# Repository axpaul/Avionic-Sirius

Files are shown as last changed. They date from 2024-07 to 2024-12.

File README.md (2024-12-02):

# Avionic-Sirius
*Sirius experimental rocket avionic (On-board electronics), Version 2024 launched at C'space*

*CC BY-NC-SA 4.0, Copyright 2023 Miailhe Paul, all rights reserved*

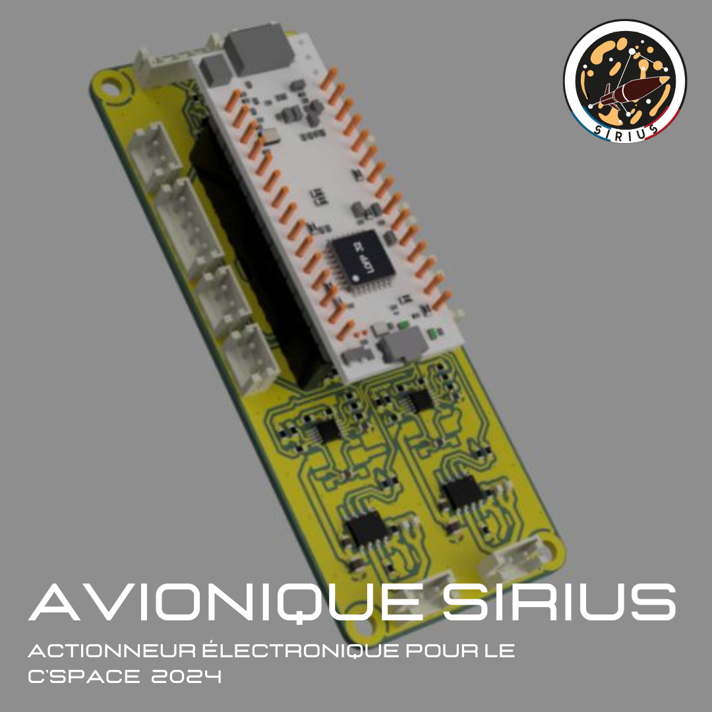
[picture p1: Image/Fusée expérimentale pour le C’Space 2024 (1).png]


# MotorShield Controller

Le **MotorShield Controller** est une carte d'actionneur conçue pour piloter deux moteurs DC. Elle intègre des circuits en pont en H et des capteurs de courant basés sur des résistances shunt, permettant la détection d'événements, la protection contre les surintensités, le contrôle PWM, ainsi que l'indication visuelle de la direction de rotation des moteurs.

---

## Composants principaux

### 1. **Hex Schmitt-Trigger Inverter (74HC14)**
- **Description** : Inverseur logique avec seuils Schmitt pour améliorer l'immunité aux bruits.  
- **Caractéristiques** :
  - Fonctionne avec des signaux LSTTL, CMOS, NMOS, et TTL.
  - Plage de tension de fonctionnement : 2.0V à 6.0V.
  - Immunité élevée au bruit et faible courant d'entrée.

---

### 2. **Optocoupleurs (ACPL-214)**
- **Description** : Optocoupleurs à gain élevé pour une isolation électrique optimale.  
- **Caractéristiques** :
  - Isolation de tension jusqu’à 3000 VRMS.

---

### 3. **Data Converter Isolator (ADuM1281)**
- **Description** : Isolateur numérique double canal pour la transmission de données.  
- **Caractéristiques** :
  - Fonctionne avec une alimentation de 3.3V.
  - Débit de données jusqu'à 100 Mbps.
  - Faible délai de propagation (23 ns).

---

### 4. **INA381A et INA381B – Détection de surintensité**
- **Description** : Amplificateurs de détection de courant avec comparateurs intégrés.  
- **Caractéristiques** :
  - Détection de courants d’entrée entre 10 mA et 3 A.
  - Seuils configurables pour les surintensités (par ex. : 1A).
  - Fonctionnement avec une tension de 3.3V.
  - Intègre une résistance de shunt de 22 mΩ pour la détection.

---

### 5. **DRV8872 – Pilote de moteur DC brossé avec rapport d’erreurs**
- **Description** : Pilote pour moteurs DC avec contrôle PWM.  
- **Caractéristiques** :
  - Plage de tension : 6.5V à 45V.
  - Courant supporté jusqu’à 3.6A.
  - Intègre des protections (UVLO, OCP, TSD) et un rapport d'état des erreurs.
  - Supporte les modes veille et actif avec contrôle de la direction et de la vitesse via PWM.

---

### 6. **Indicateurs LED de direction du moteur**
- **Description** : Circuit simple avec LEDs et résistances pour indiquer la direction de rotation du moteur.  
- **Caractéristiques** :
  - Confirmation visuelle de la rotation du moteur sans connexion supplémentaire.
  - Permet de tester et de vérifier facilement la logique de contrôle.

---

### 7. **Configuration en pont (JP5)**
- **Description** : Jumper configurable pour définir les fonctionnalités d'entrée ou de sortie.  
- **Caractéristiques** :
  - Évite les conflits d’assignation en définissant clairement les modes de fonctionnement.
 
## Licence 



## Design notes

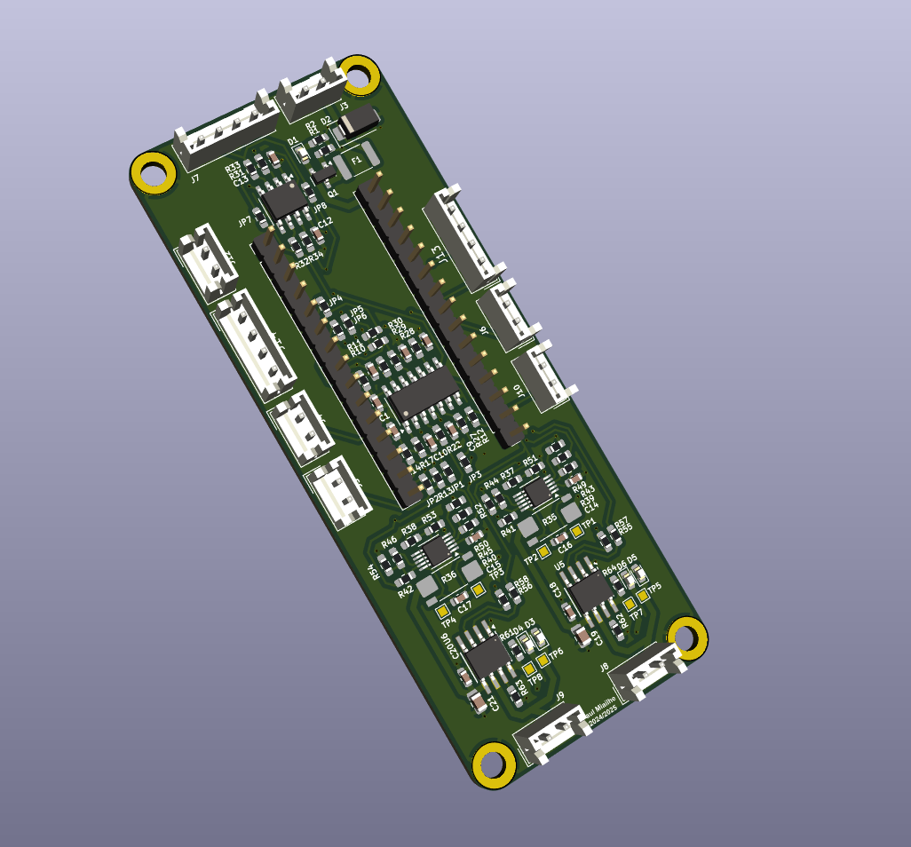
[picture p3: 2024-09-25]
Image/image.png

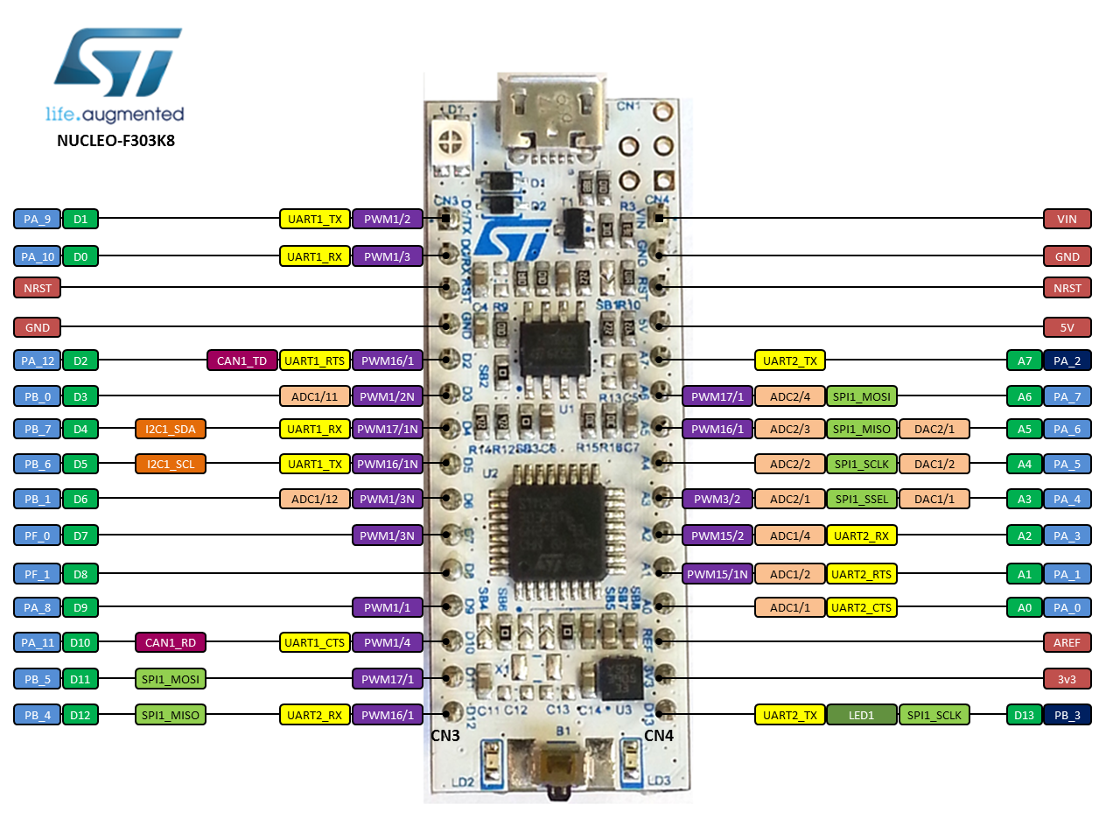
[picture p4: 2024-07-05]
Current-Sensor/nucleo_f303k8_2017_10_10.png

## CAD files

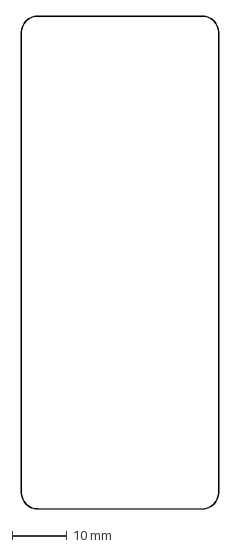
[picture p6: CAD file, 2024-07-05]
PCB-N2.dxf
36.0 x 90.0 mm

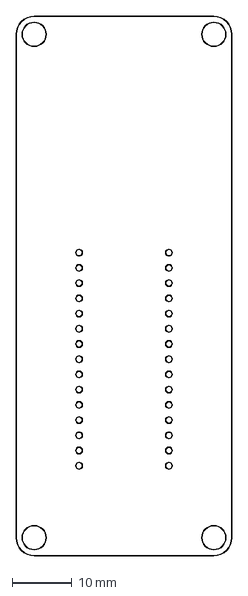
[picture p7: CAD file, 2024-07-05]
PCB-N1.dxf
36.0 x 90.0 mm

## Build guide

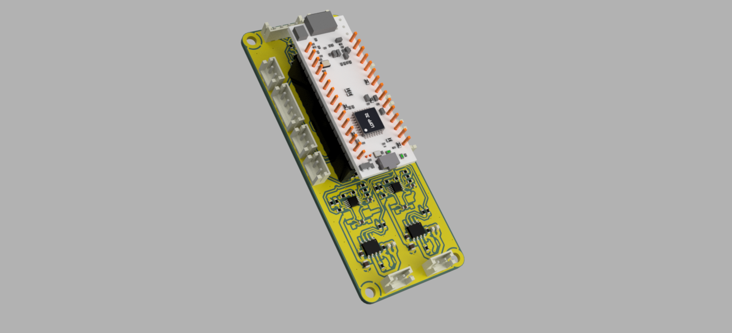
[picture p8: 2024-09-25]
Image/Assemblage_v10.png

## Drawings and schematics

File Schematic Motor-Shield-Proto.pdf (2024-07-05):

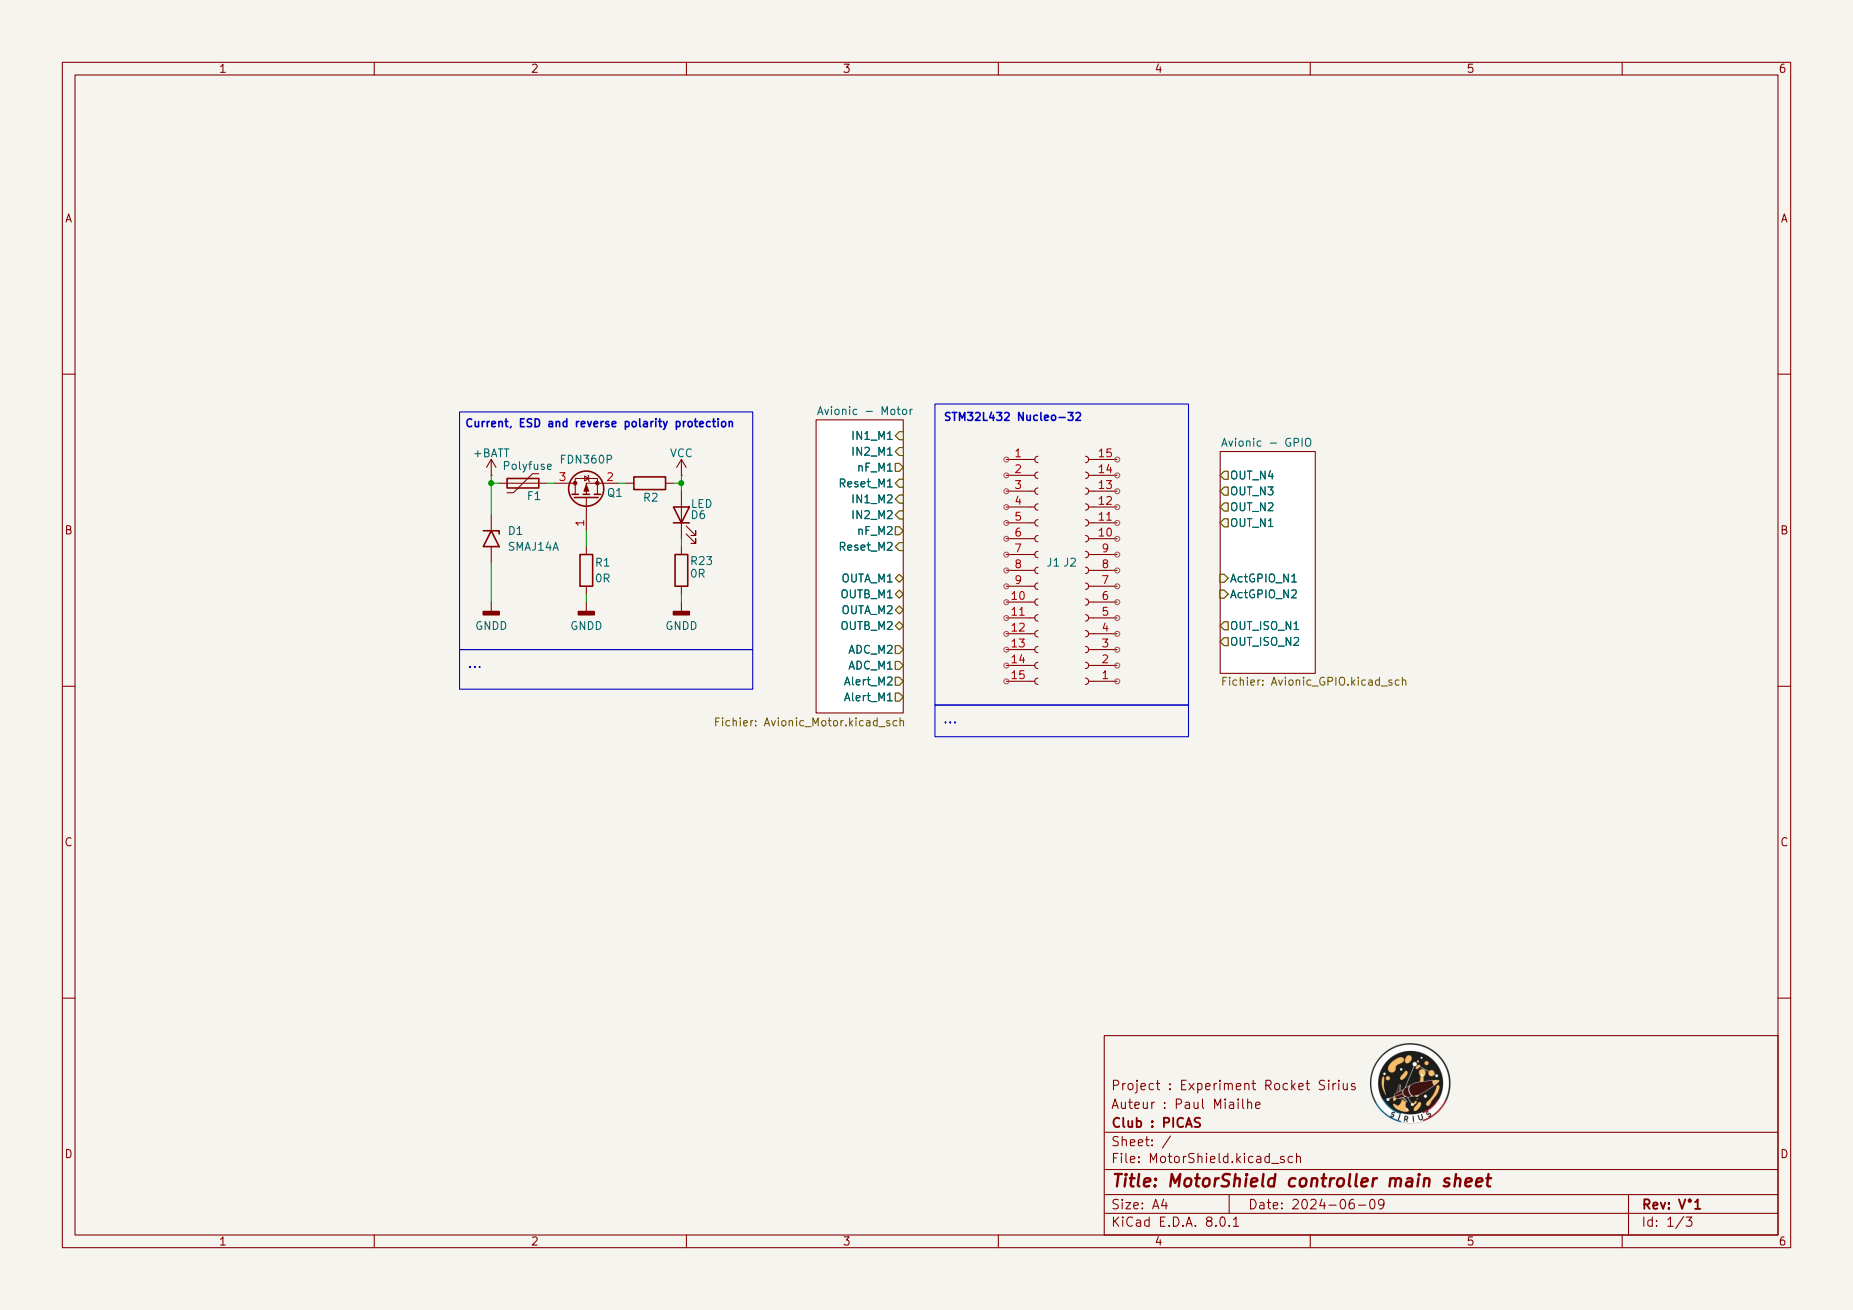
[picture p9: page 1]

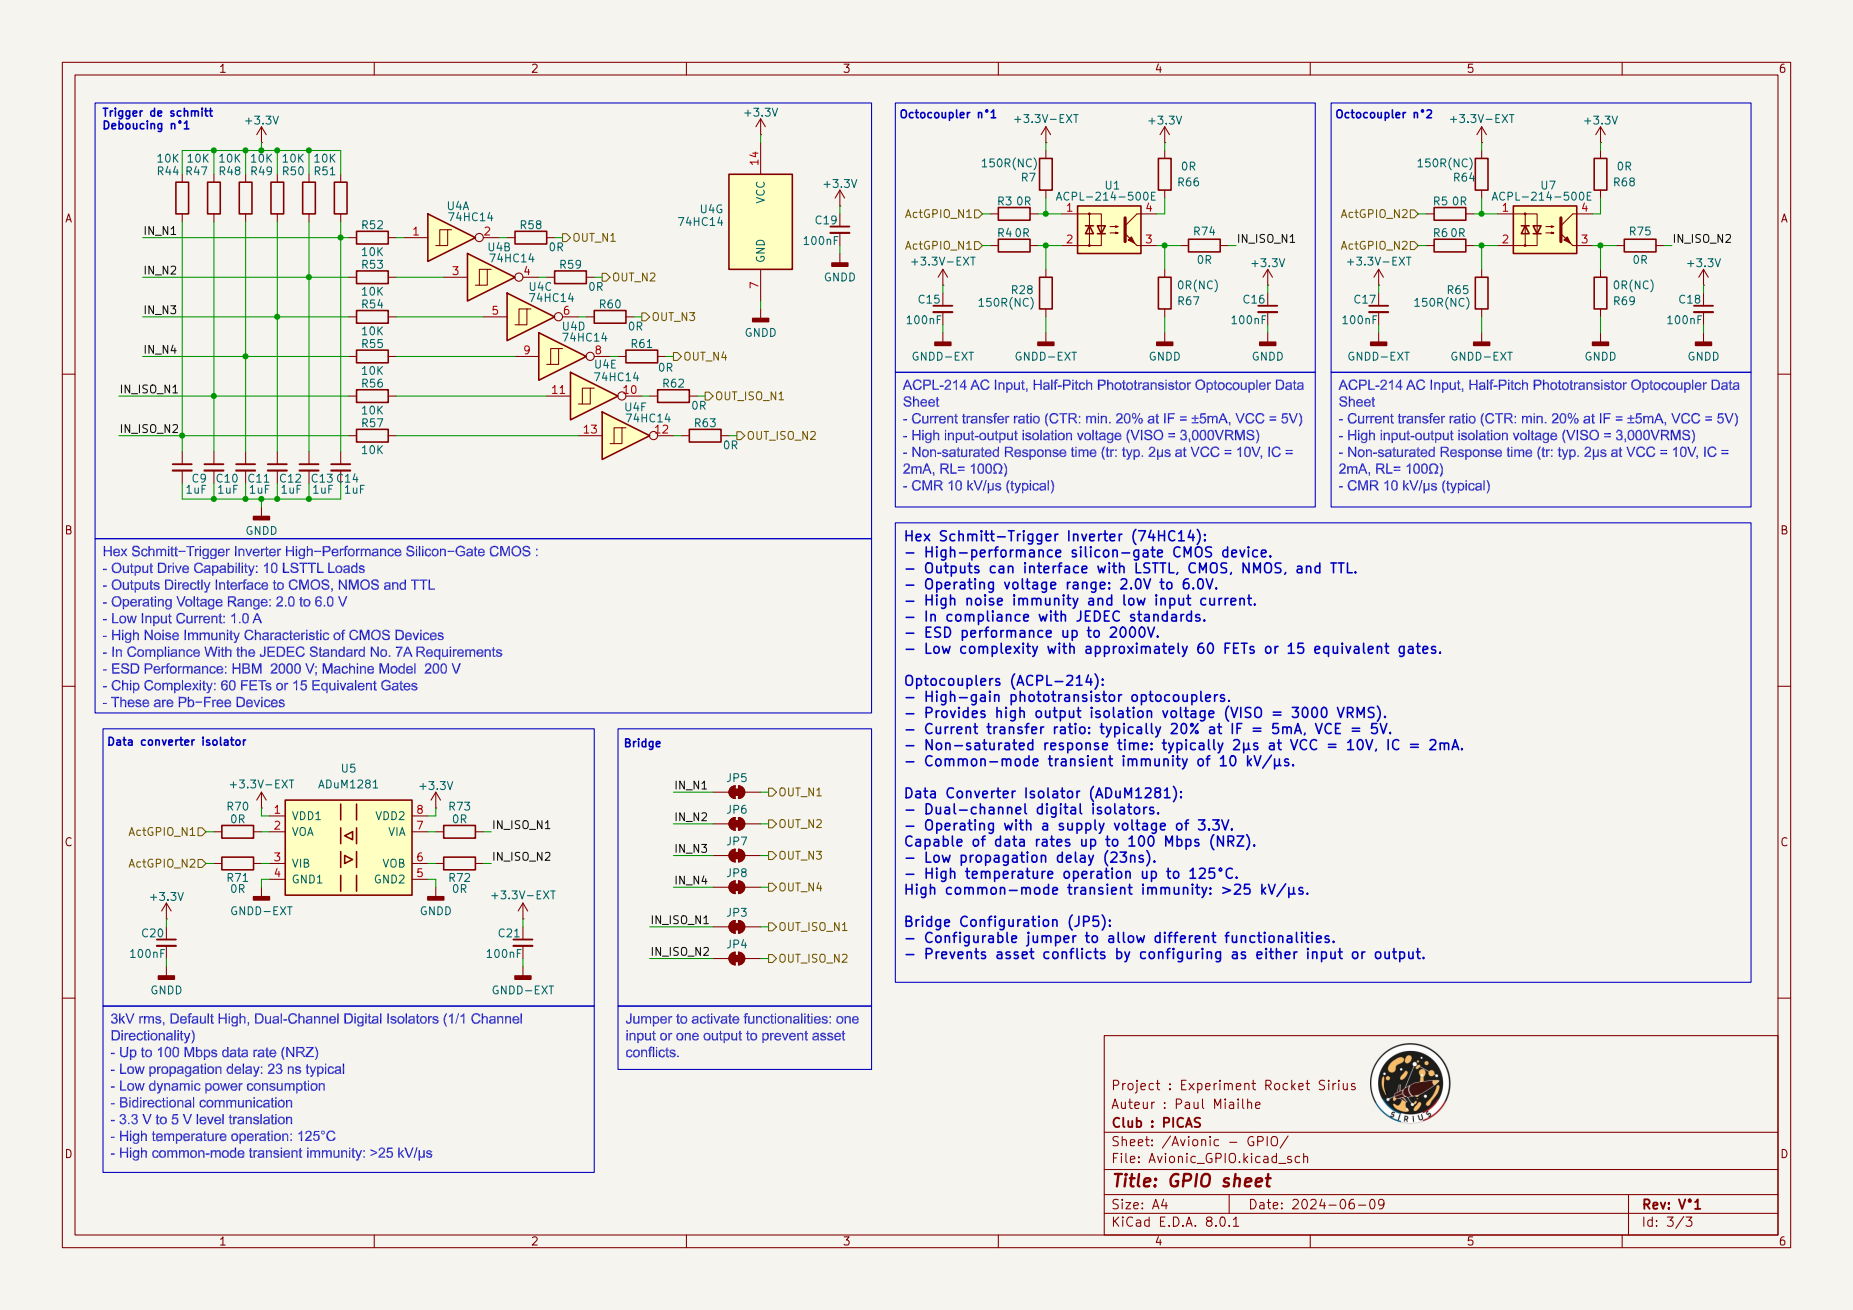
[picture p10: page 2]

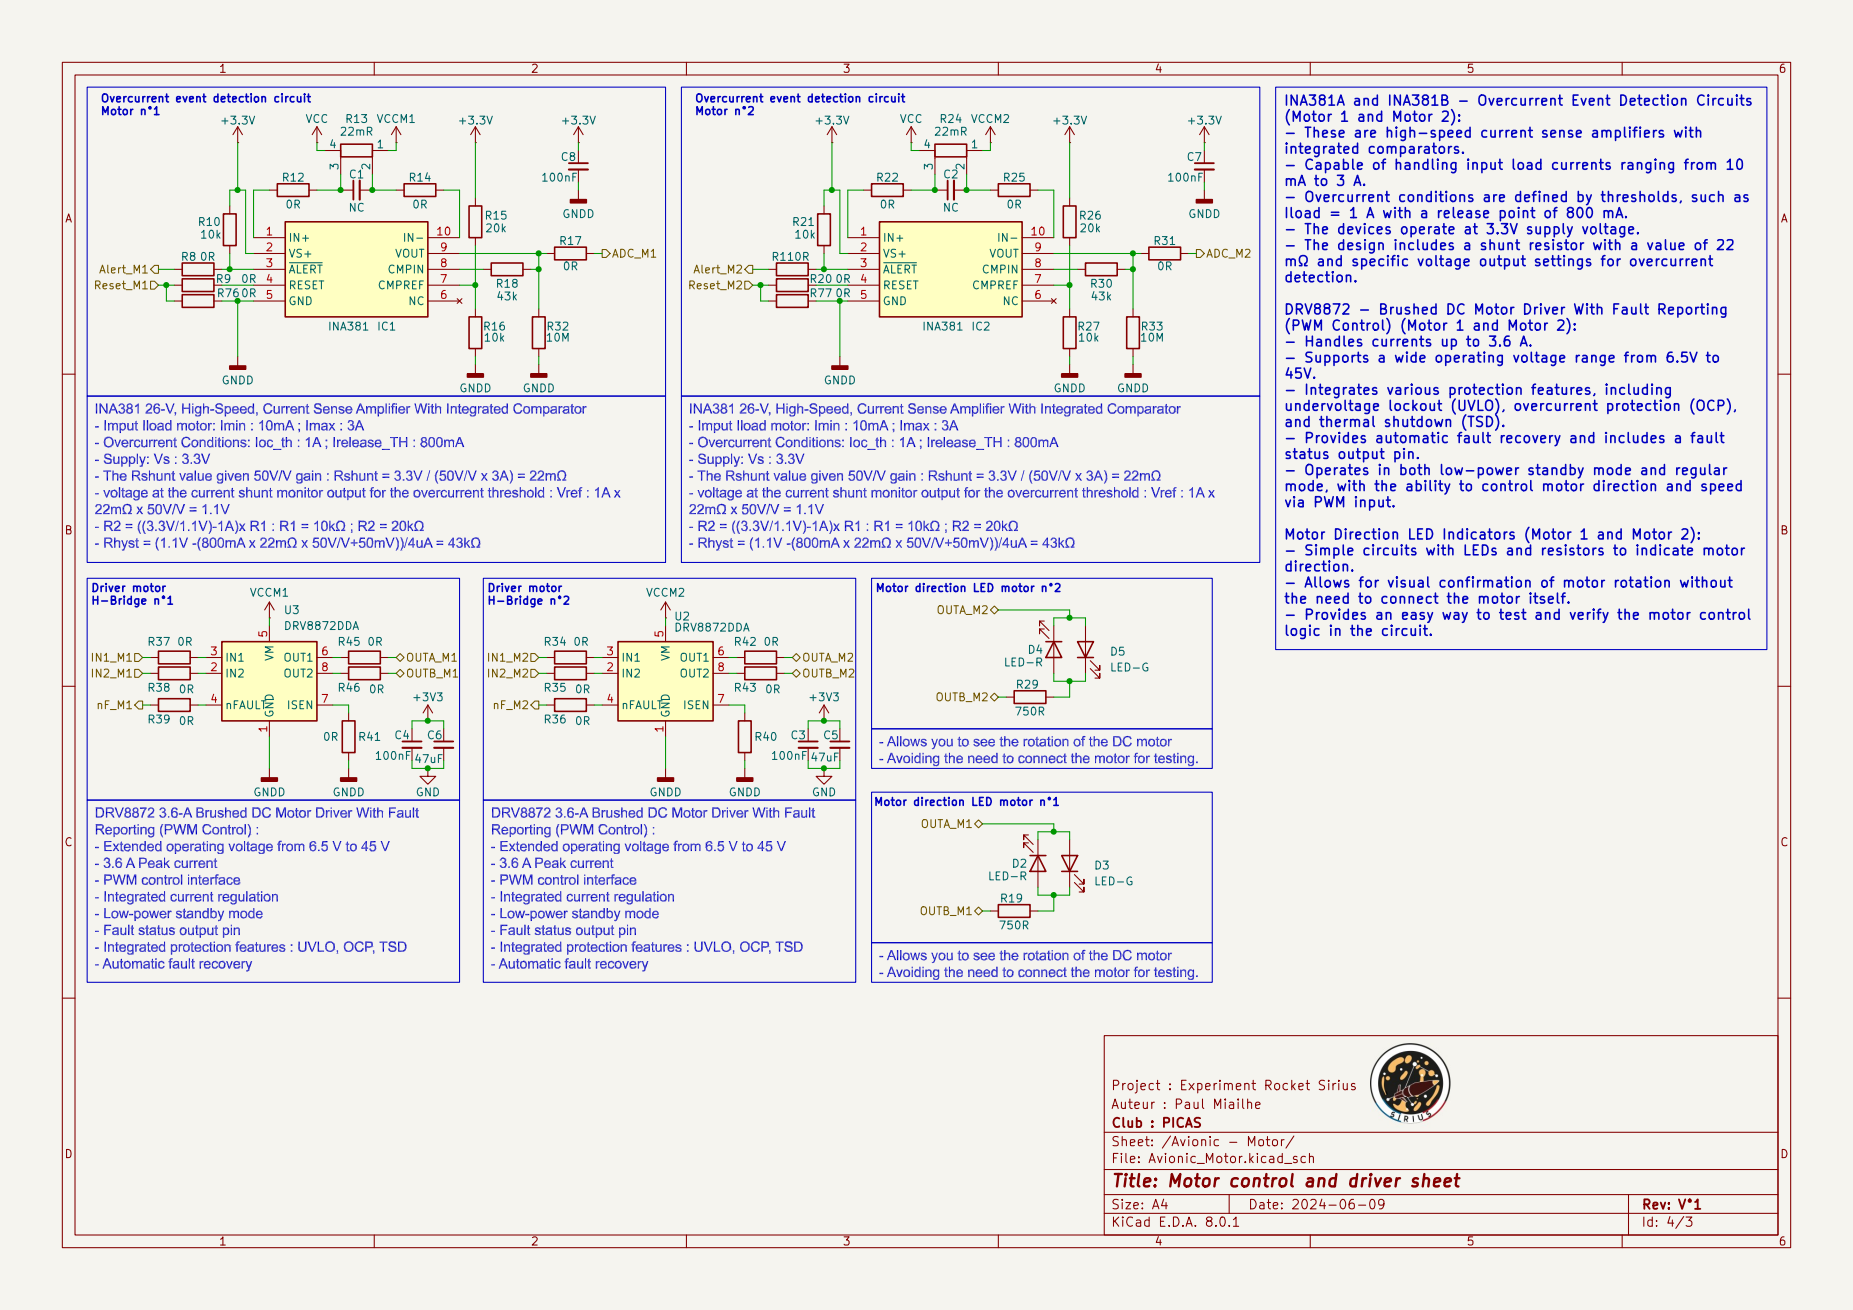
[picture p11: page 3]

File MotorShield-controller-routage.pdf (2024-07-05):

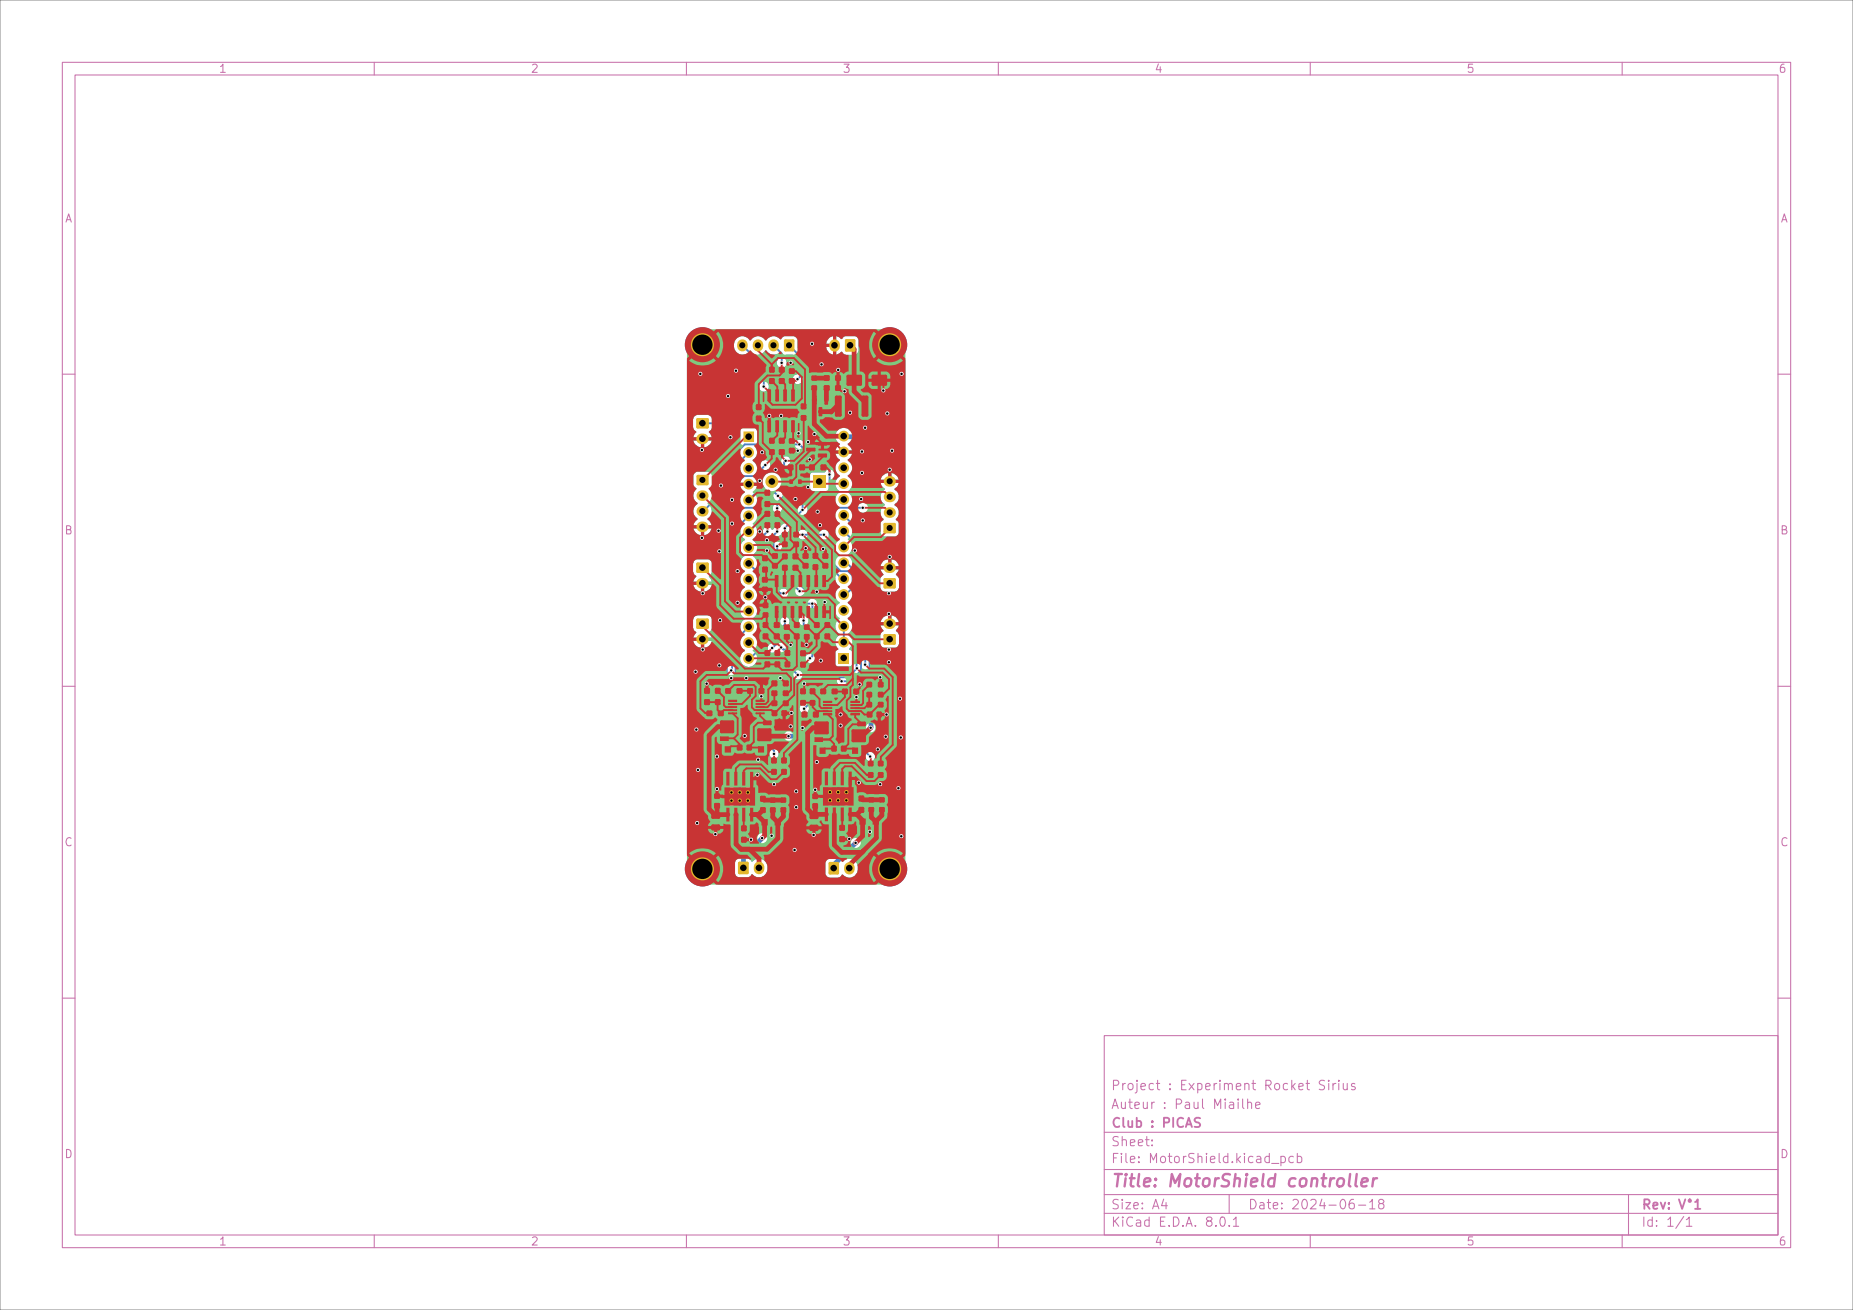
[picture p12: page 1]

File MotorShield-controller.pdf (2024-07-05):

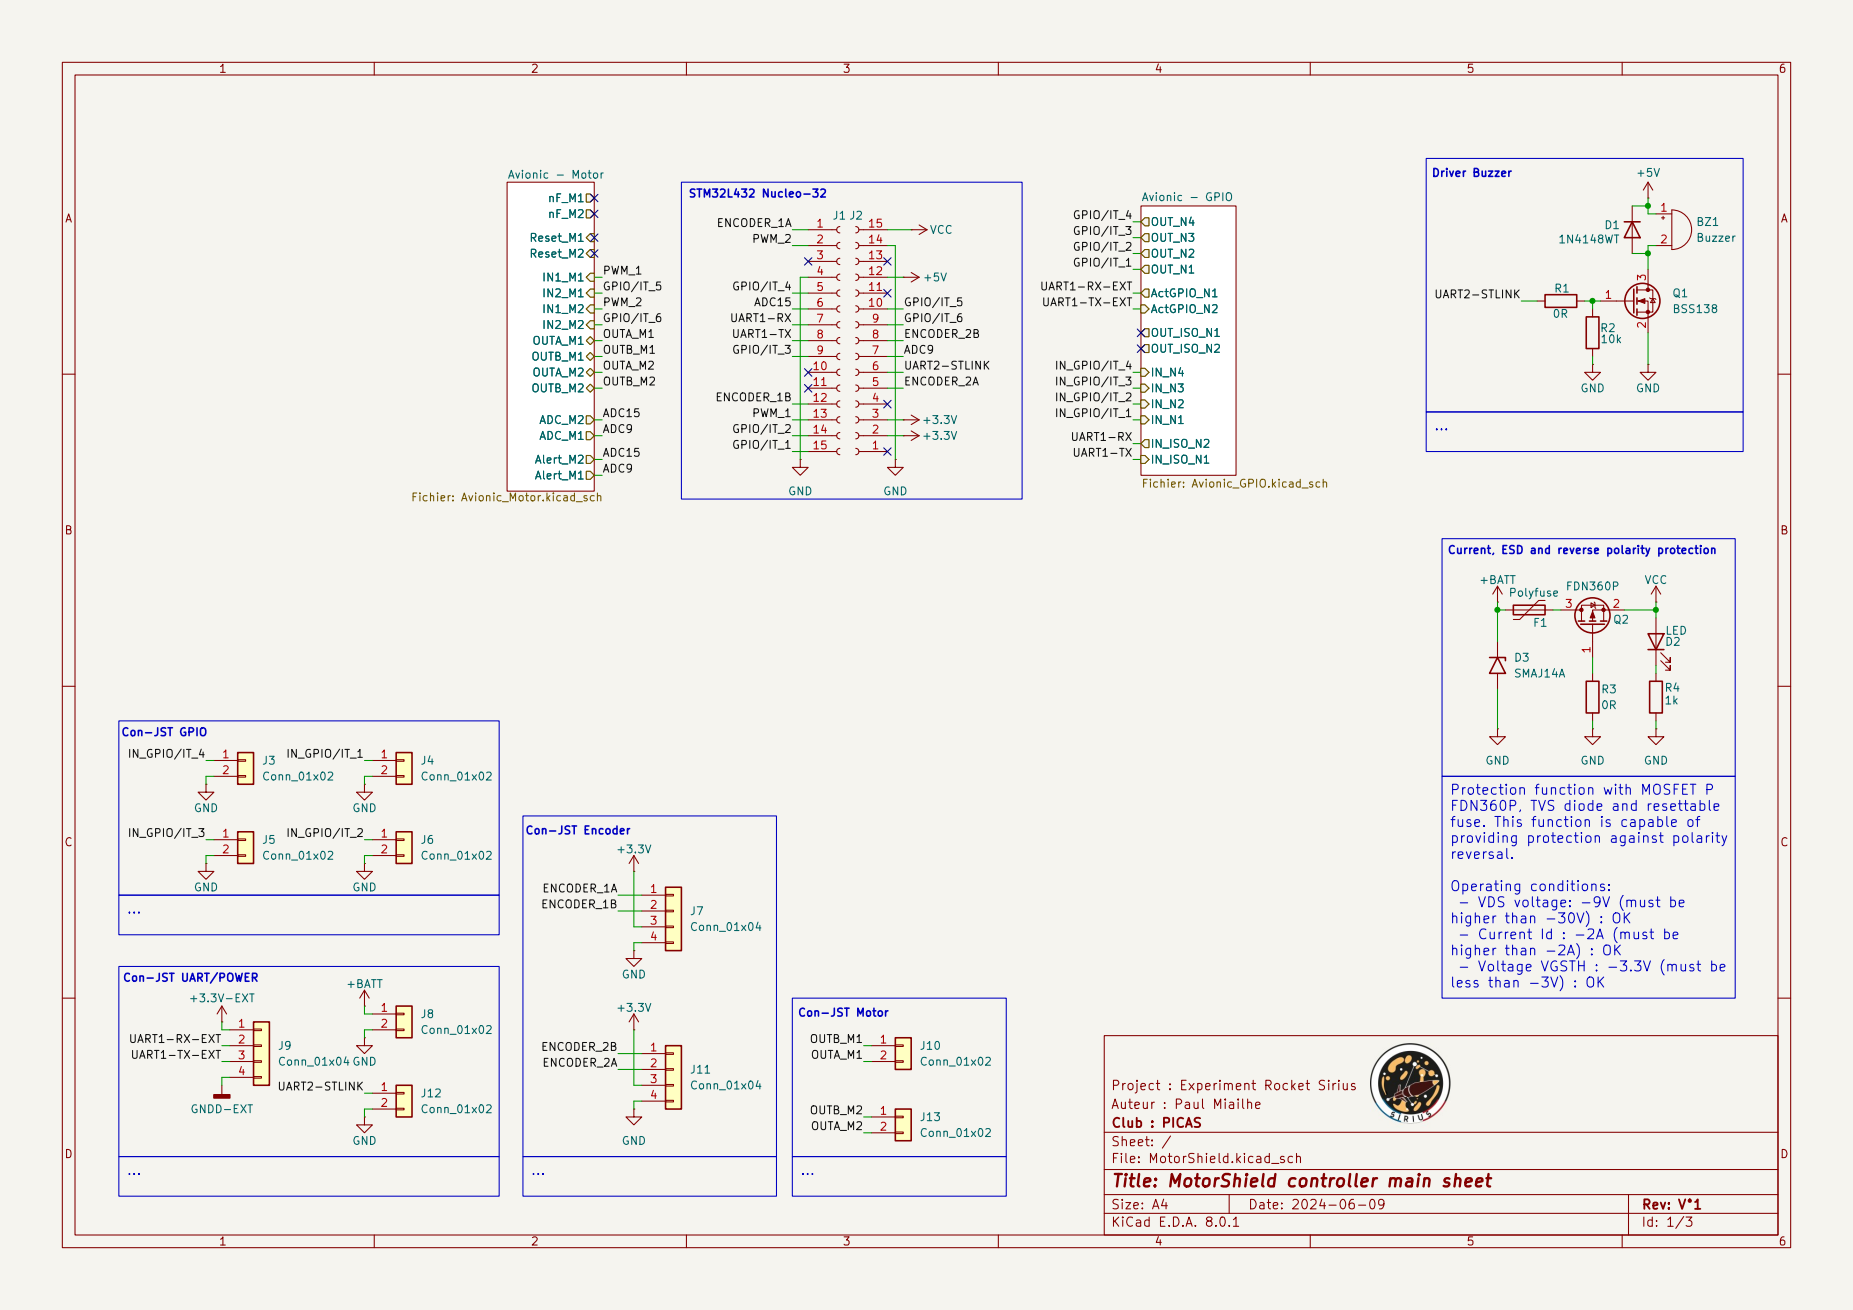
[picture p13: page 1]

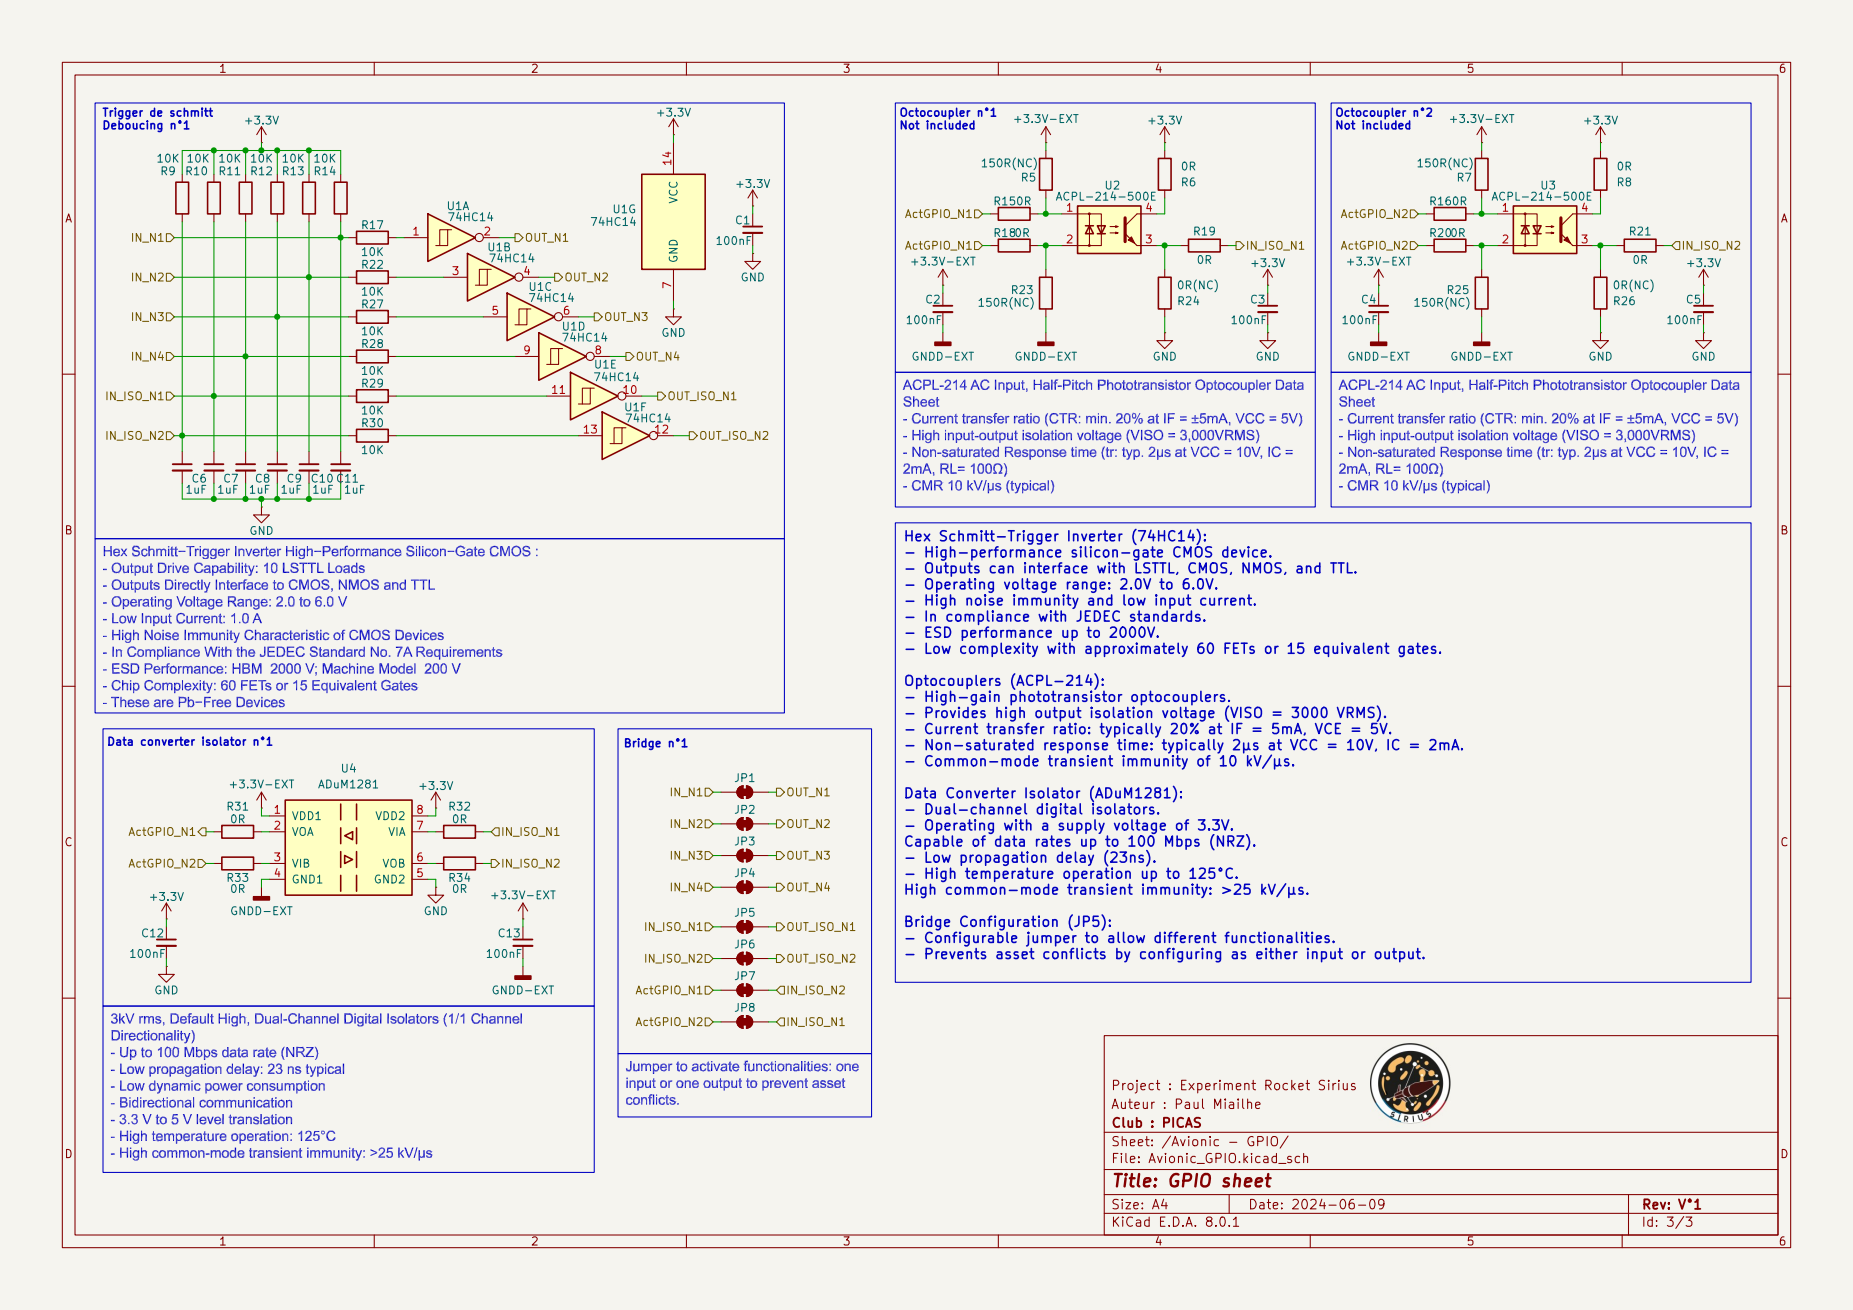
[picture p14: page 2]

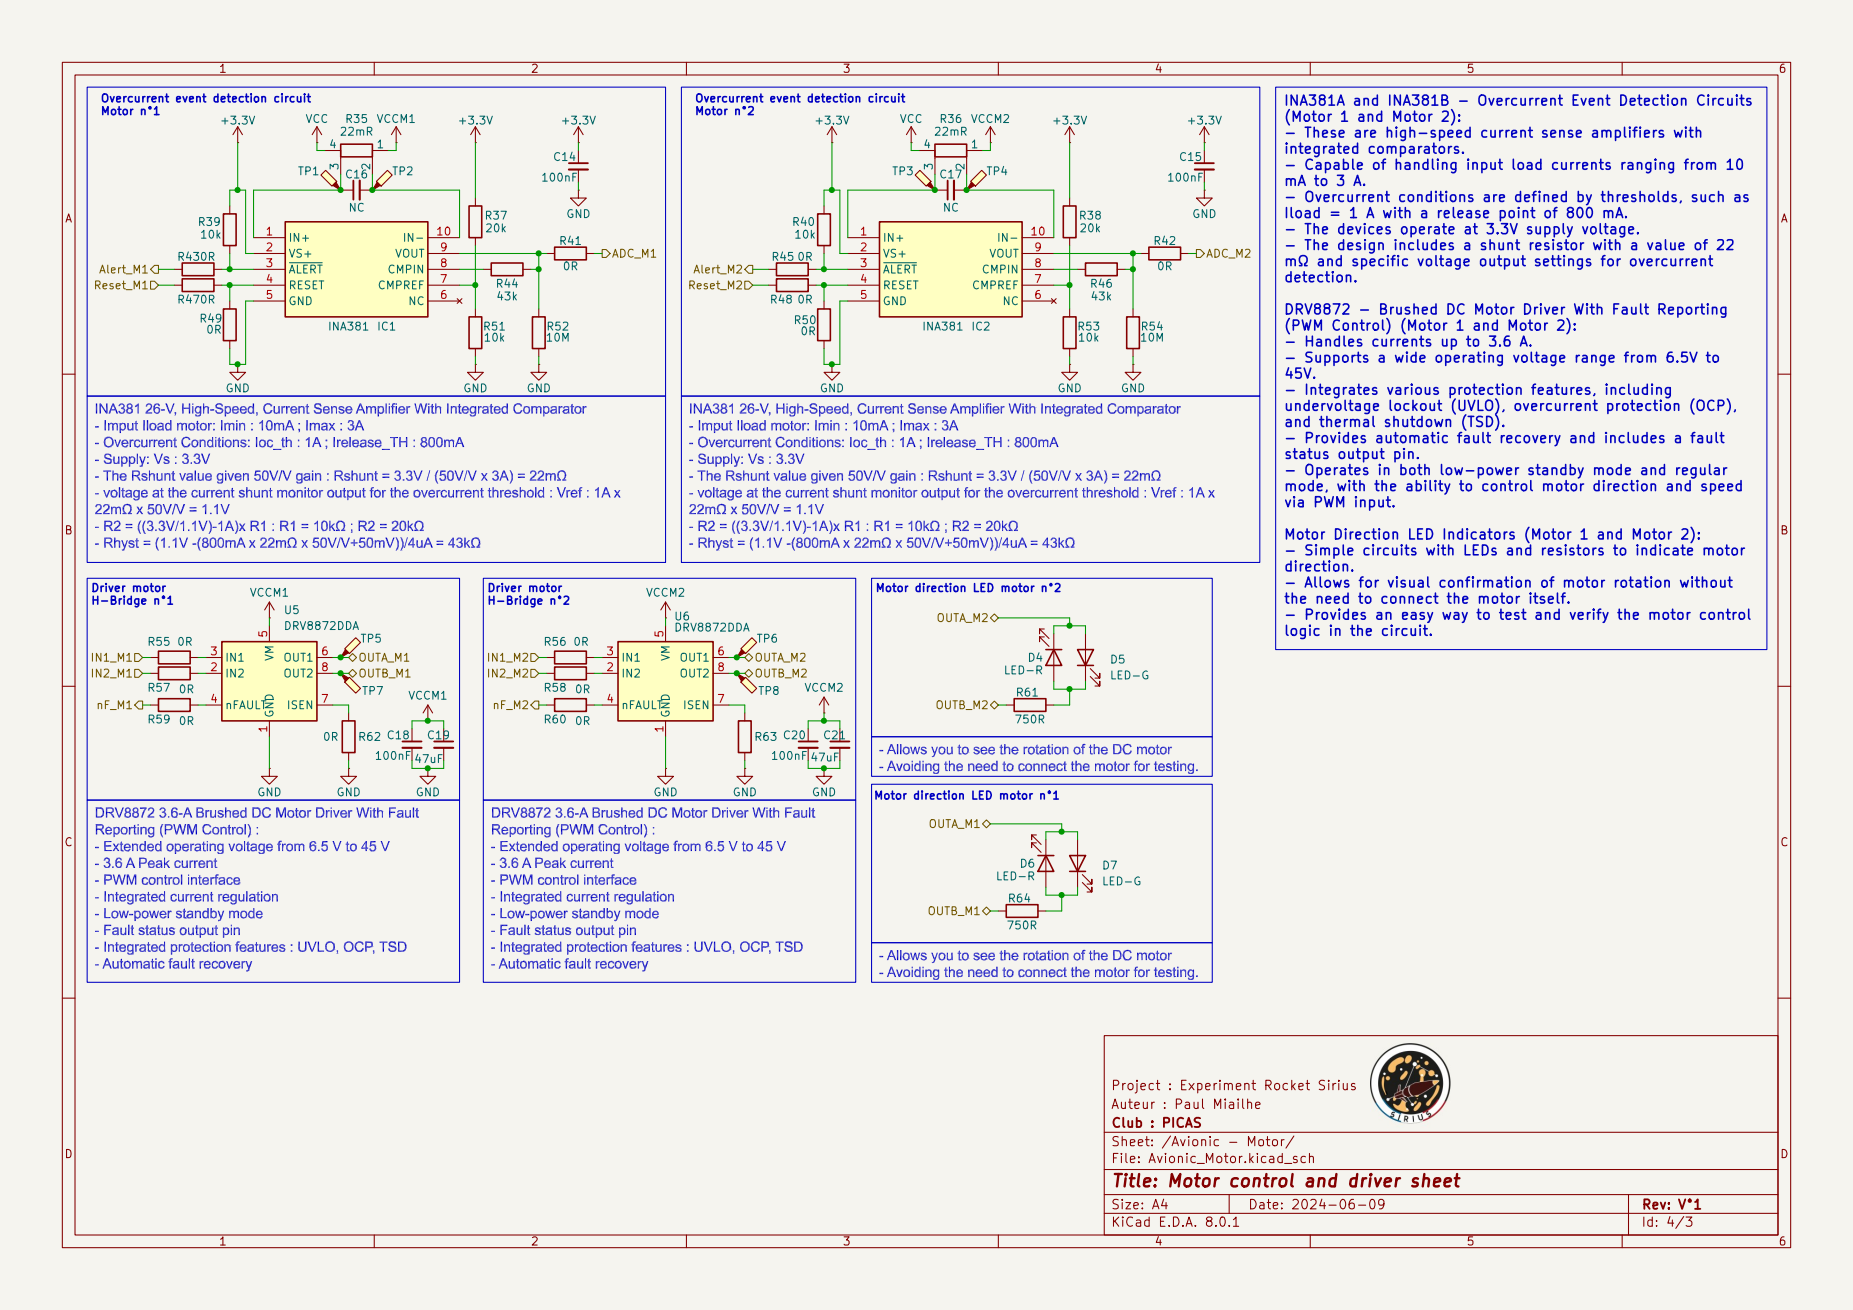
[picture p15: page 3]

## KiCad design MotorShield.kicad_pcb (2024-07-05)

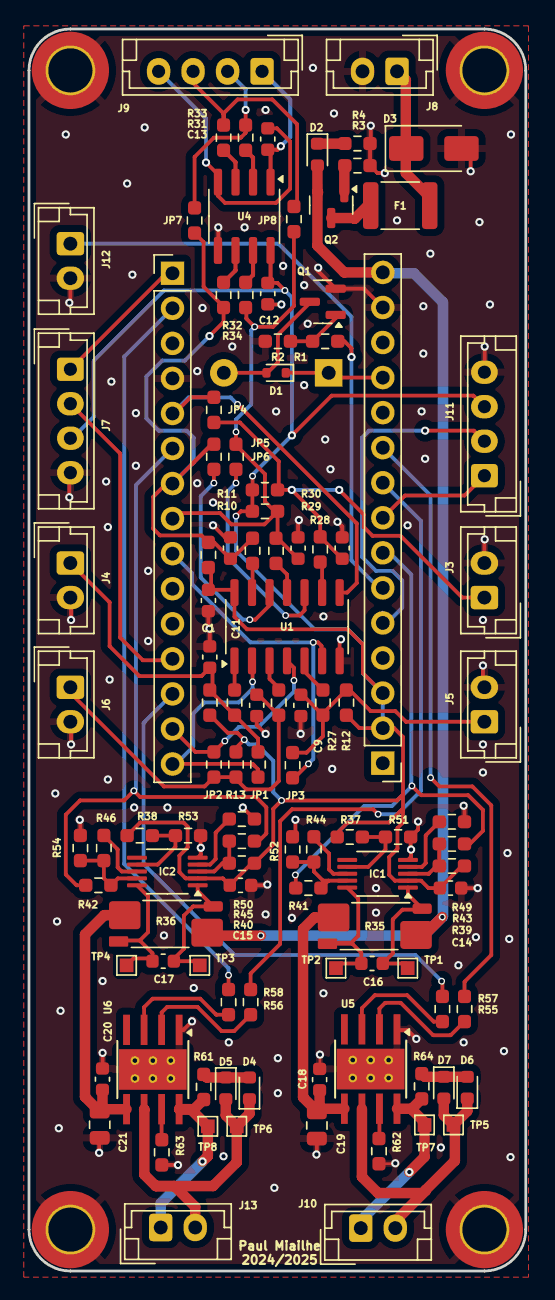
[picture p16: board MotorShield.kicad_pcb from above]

Board: 4 copper layers, 36.0 x 90.0 mm, 109 parts (1 on the bottom side), 75 nets.

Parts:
BZ1: Buzzer; Buzzer_12x9.5RM7.6
C1, C12, C13, C14, C15, C18, C20: 100nF; C_0603_1608Metric
C6, C7, C8, C9, C10, C11: 1uF; C_0603_1608Metric
C16, C17: NC; C_0603_1608Metric
C19, C21: 47uF; C_0805_2012Metric
D1: 1N4148WT; D_SOD-523
D2: LED; LED_0603_1608Metric
D3: SMAJ14A; D_SMA
D4, D6: LED-R; LED_0603_1608Metric
D5, D7: LED-G; LED_0603_1608Metric
F1: Polyfuse; Fuse_1812_4532Metric
IC1, IC2: INA381; VSSOP-10_3x3mm_P0.5mm
J1, J2: Conn_01x15_Socket; PinHeader_1x15_P2.54mm_Vertical
J3, J4, J5, J6, J8, J10, J12, J13: Conn_01x02; JST_EH_B2B-EH-A_1x02_P2.50mm_Vertical
J7, J9, J11: Conn_01x04; JST_EH_B4B-EH-A_1x04_P2.50mm_Vertical
JP1, JP2, JP3, JP4, JP5, JP6, JP7, JP8: SolderJumper; R_0603_1608Metric_Pad0.98x0.95mm_HandSolder
Q1: BSS138; SOT-23
Q2: FDN360P; SOT-23
R1, R3, R31, R32, R33, R34, R41, R42, R43, R45, R49, R50, R55, R56, R57, R58, R62, R63: 0R; R_0603_1608Metric_Pad0.98x0.95mm_HandSolder
R2, R39, R40, R51, R53: 10k; R_0603_1608Metric_Pad0.98x0.95mm_HandSolder
R4: 1k; R_0603_1608Metric_Pad0.98x0.95mm_HandSolder
R9, R10, R11, R12, R13, R14, R17, R22, R27, R28, R29, R30: 10K; R_0603_1608Metric_Pad0.98x0.95mm_HandSolder
R35, R36: 22mR; R_Shunt_Vishay_WSK2512_6332Metric_T1.19mm
R37, R38: 20k; R_0603_1608Metric_Pad0.98x0.95mm_HandSolder
R44, R46: 43k; R_0603_1608Metric_Pad0.98x0.95mm_HandSolder
R52, R54: 10M; R_0603_1608Metric_Pad0.98x0.95mm_HandSolder
R61, R64: 750R; R_0603_1608Metric_Pad0.98x0.95mm_HandSolder
TP1, TP2, TP3, TP4, TP5, TP6, TP7, TP8: TestPoint_Probe; TestPoint_Pad_1.0x1.0mm
U1: 74HC14; SOIC-14_3.9x8.7mm_P1.27mm
U4: ADuM1281; SOIC-8_3.9x4.9mm_P1.27mm
U5, U6: DRV8872DDA; Texas_HTSOP-8-1EP_3.9x4.9mm_P1.27mm_EP2.95x4.9mm_Mask2.4x3.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

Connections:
+3.3V: C1.1, C12.1, C14.1, C15.1, IC1.2 (VS+), IC2.2 (VS+), J2.2, J2.3, J7.3, J11.3, R9.1, R10.1, R11.1, R12.1, R13.1, R14.1, R37.2, R38.2, R39.2, R40.2, U1.14 (VCC), U4.8 (VDD2)
+3.3V-EXT: C13.1, J9.1, U4.1 (VDD1)
+5V: BZ1.1 (+), D1.1 (K), J2.12
+BATT: D3.1 (A1), F1.1, J8.1
/ADC9: J2.7, R41.1, R43.1
/ADC15: J1.6, R42.1, R45.1
/Avionic - GPIO/OUT_ISO_N1: JP5.2 (B), U1.10
/Avionic - GPIO/OUT_ISO_N2: JP6.2 (B), U1.12
/ENCODER_1A: J1.1, J7.1
/ENCODER_1B: J1.12, J7.2
/ENCODER_2A: J2.5, J11.2
/ENCODER_2B: J2.8, J11.1
/GPIO/IT_1: J1.15, JP1.2 (B), U1.2
/GPIO/IT_2: J1.14, JP2.2 (B), U1.4
/GPIO/IT_3: J1.9, JP3.2 (B), U1.6
/GPIO/IT_4: J1.5, JP4.2 (B), U1.8
/GPIO/IT_5: J2.10, R57.1
/GPIO/IT_6: J2.9, R58.1
/IN_GPIO/IT_1: C11.1, J4.1, JP1.1 (A), R14.2, R17.2
/IN_GPIO/IT_2: C10.1, J6.1, JP2.1 (A), R13.2, R22.2
/IN_GPIO/IT_3: C9.1, J5.1, JP3.1 (A), R12.2, R27.2
/IN_GPIO/IT_4: C8.1, J3.1, JP4.1 (A), R11.2, R28.2
/OUTA_M1: D6.1 (K), D7.2 (A), J10.2, TP5.1, U5.6 (OUT1)
/OUTA_M2: D4.1 (K), D5.2 (A), J13.2, TP6.1, U6.6 (OUT1)
/OUTB_M1: J10.1, R64.1, TP7.1, U5.8 (OUT2)
/OUTB_M2: J13.1, R61.1, TP8.1, U6.8 (OUT2)
/PWM_1: J1.13, R55.1
/PWM_2: J1.2, R56.1
/UART1-RX: C6.1, J1.7, JP6.1 (A), JP7.2 (B), R9.2, R30.2, R34.2
/UART1-RX-EXT: J9.2, JP7.1 (A), R31.1
/UART1-TX: C7.1, J1.8, JP5.1 (A), JP8.2 (B), R10.2, R29.2, R32.2
/UART1-TX-EXT: J9.3, JP8.1 (A), R33.1
/UART2-STLINK: J2.6, J12.1, R1.1
GND: C1.2, C6.2, C7.2, C8.2, C9.2, C10.2, C11.2, C12.2, C14.2, C15.2, C18.2, C19.2, C20.2, C21.2, D3.2 (A2), IC1.5 (GND), IC2.5 (GND), J1.4, J2.14, J3.2, J4.2, J5.2, J6.2, J7.4, J8.2, J11.4, J12.2, Q1.2 (S), R2.1, R3.2, R4.2, R49.1, R50.1, R51.1, R52.1, R53.1, R54.1, R62.1, R63.1, U1.7 (GND), U4.5 (GND2), U5.1 (GND), U5.9 (GND), U6.1 (GND), U6.9 (GND)
GNDD-EXT: C13.2, J9.4, U4.4 (GND1)
unnamed: BZ1.2 (-), D1.2 (A), Q1.3 (D)
unnamed: D2.1 (K), R4.1
unnamed: D4.2 (A), D5.1 (K), R61.2
unnamed: D6.2 (A), D7.1 (K), R64.2
unnamed: IC1.8 (CMPIN), R44.2
unnamed: IC1.7 (CMPREF), R37.1, R51.2
unnamed: C16.1, IC1.1 (IN+), R35.3, TP1.1
unnamed: C16.2, IC1.10 (IN-), R35.2, TP2.1
unnamed: IC1.4 (RESET), R49.2
unnamed: IC1.9 (VOUT), R41.2, R44.1, R52.2
unnamed: IC1.3 (~ALERT), R39.1, R43.2
unnamed: IC2.8 (CMPIN), R46.2
unnamed: IC2.7 (CMPREF), R38.1, R53.2
unnamed: C17.1, IC2.1 (IN+), R36.3, TP3.1
unnamed: C17.2, IC2.10 (IN-), R36.2, TP4.1
unnamed: IC2.4 (RESET), R50.2
unnamed: IC2.9 (VOUT), R42.2, R46.1, R54.2
unnamed: IC2.3 (~ALERT), R40.1, R45.2
unnamed: Q1.1 (G), R1.2, R2.2
unnamed: F1.2, Q2.3 (D)
unnamed: Q2.1 (G), R3.1
unnamed: R17.1, U1.1
unnamed: R22.1, U1.3
unnamed: R27.1, U1.5
unnamed: R28.1, U1.9
unnamed: R29.1, U1.11
unnamed: R30.1, U1.13
unnamed: R32.1, U4.7 (VIA)
unnamed: R33.2, U4.3 (VIB)
unnamed: R31.2, U4.2 (VOA)
unnamed: R34.1, U4.6 (VOB)
unnamed: R55.2, U5.3 (IN1)
unnamed: R57.2, U5.2 (IN2)
unnamed: R62.2, U5.7 (ISEN)
unnamed: R56.2, U6.3 (IN1)
unnamed: R58.2, U6.2 (IN2)
unnamed: R63.2, U6.7 (ISEN)
VCC: D2.2 (A), J2.15, Q2.2 (S), R35.4, R36.4
VCCM1: C18.1, C19.1, R35.1, U5.5 (VM)
VCCM2: C20.1, C21.1, R36.1, U6.5 (VM)

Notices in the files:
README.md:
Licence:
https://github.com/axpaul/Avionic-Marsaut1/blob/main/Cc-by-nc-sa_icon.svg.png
